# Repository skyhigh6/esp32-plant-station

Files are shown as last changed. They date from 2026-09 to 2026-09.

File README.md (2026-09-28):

# Plant Station — R17

Arduino Uno plant station prototype. Current design **R17**, controlled document issue **D02**, firmware **Uno UI v6**. Physical fit and electrical acceptance remain open.

## Start here

- [Project control and acceptance gates](PROJECT_CONTROL.md)
- [Illustrated assembly manual — PLANT-AM-001](docs/documents/AM_R17/PLANT-AM-001_R17_D02.pdf)
- [Design review — PLANT-TR-001](docs/documents/TR_R17/PLANT-TR-001_R17_D02.pdf)
- [Test and acceptance sheets — PLANT-TS-001](docs/documents/TS_R17/PLANT-TS-001_R17_D02.pdf)
- [Complete R17 download](releases/R17/Plant_Station_R17_D02.zip)
- [Document index](docs/START_HERE.html) and [operator wiring view](docs/operator_view.html) — download and open locally

## Repository structure

| Folder | Contents |
|---|---|
| `technical/cad/` | Current R17 generator, parameters, frozen STEP input and independent checker |
| `technical/print/` | 4 main parts, 11 fit trials, 8 knob choices; matching STL and STEP, source hashes, four-plate layout and four operator slicer exports |
| `firmware/` | Current Uno sketch, adjacent headers, host assertions and build instructions |
| `docs/` | Three illustrated PDFs, editable JSON/Markdown, assets, page renders and document controls |
| `references/` | Supplied USB dimension image and illustration provenance |
| `verification/` | CAD/document results, selected predecessor source basis and release checks |
| `releases/R17/` | Frozen complete package and SHA-256 manifest |
| `scripts/` | Portable document rebuild, export verification and packaging tools |

The tower replaces the broad USB cable opening with an estimated **9.8 × 4.2 mm** USB-C aperture, **Ø2.8 mm** fixing pilots at **15.2 mm** pitch, and an adjacent **Ø10 mm** DC-extension hole. Print the port coupon first. USB dimensions are authorised estimates; actual fit has not been tested.

Use the R17 tower, retained R16 lid carrying R15 geometry, retained R13 fascia/planter and **one** suitable knob. Revision suffixes identify part provenance. Do not print all alternatives.

The [four-plate Bambu Studio layout](technical/print/plate_layout/r17_plate_layout.3mf) contains the four main models. Its component geometry matches the released STL files; print settings and physical results remain unvalidated. Financial fields and an account identifier were removed from the publication copy; the original is retained locally.

The [operator slicer exports](technical/print/slicer_exports/README.md) contain four separately exported printer files. Their executable commands are preserved, with source/publication hashes and metadata changes recorded. Their inclusion records the supplied files; it does not approve their settings or physical operation.

## Traceability

`PROJECT_CONTROL.md` is the single current baseline pointer. The D02 manuals carry revision history, effective-page lists and source-backed change bars. The [print manifest](technical/print/manifest.json) identifies every selected export. The [evidence register](docs/control/evidence_register.json) identifies the documentary source basis; snapshot records are historical evidence, not current instructions.

Superseded release folders and archives have been removed from the current branch tree. Git history retains published predecessors; a verified external local backup preserves unpublished work. Repository visibility and existing history are unchanged.

## Rebuild and verify

See [document instructions](docs/README.md), [CAD instructions](technical/cad/README.md), [firmware instructions](firmware/README.md) and [verification scope](verification/README.md).

```powershell
python scripts/rebuild_documents.py
python scripts/verify_release.py
python scripts/package_release.py
```

Requires Python 3.12 and the libraries listed in `requirements-docs.txt` and `requirements-cad.txt`. The CAD runtime has a recorded shutdown exit-code anomaly; the independent export checker remains a separate gate. No physical, powered, wet or printer acceptance is implied by publication.

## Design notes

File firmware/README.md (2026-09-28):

# Arduino Uno firmware — UI v6

Current source: `arduino/PlantUno/PlantUno.ino`, with adjacent `PlantController.h` and `PlantView.h`. Target: classic ATmega328P Arduino Uno; the sketch rejects other board profiles.

## Interface

| Pin | Connection |
|---|---|
| D2 / D3 / D4 | WATER / NEXT SCREEN and held lamp test / STOP; INPUT_PULLUP switches to GND |
| D5 / D6 / D7 | Red / yellow / green lamp outputs, each with a verified current limit |
| D9 | Enabled active-HIGH relay module input; module behaviour is user reported |
| A0 / A1 | Soil signal / dose potentiometer |
| A4 / A5 | LCD SDA / SCL; LCD VCC on regulated 5 V and GND |
| D10 | Unconnected; LCD backlight controlled over I²C |

A1 is sampled once at dose start for 1,000–4,000 ms. STOP or lamp test cancels; all buttons must be released before another dose. Soil indication is advisory; no automatic watering. The screen returns to soil status after a dose; backlight turns off after 60 s idle and wakes on input activity.

See the [operator view](../docs/operator_view.html) and [current assembly manual](../docs/documents/AM_R17/PLANT-AM-001_R17_D02.pdf) for wiring, lead identification and holds. The separate pump supply, actual relay/input characteristics and current limits need physical verification. Software STOP does not isolate power.

## Target build

Install Arduino AVR core and Bill Perry's `hd44780` library. The controlled source record distinguishes the historical build/upload evidence from physical acceptance. No new upload is performed by this release.

```powershell
arduino-cli compile --fqbn arduino:avr:uno firmware/arduino/PlantUno
```

Before any separately authorised upload or powered test, confirm the pump supply is OFF and re-detect the actual serial port.

## Host assertions

The tests include the same controller/view headers as the current Uno sketch. They cover debounce, sampled duration and bounds, STOP/lamp priority, release/lockout, clock rollover, soil fault/threshold indications, UI pages and backlight timing. They do not execute AVR GPIO/I²C or prove physical hardware operation.

```powershell
New-Item -ItemType Directory -Force .build | Out-Null
g++ -std=c++17 -Wall -Wextra -Werror firmware/test/plant_controller_tests.cpp -o .build/controller_tests.exe
g++ -std=c++17 -Wall -Wextra -Werror firmware/test/plant_view_tests.cpp -o .build/view_tests.exe
.build/controller_tests.exe
.build/view_tests.exe
```

The original UI v6 sketch and both adjacent headers are preserved byte-for-byte in this reorganisation. The older competing ESP32 controller implementation has been retired from the current tree.

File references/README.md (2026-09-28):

# Technical reference material

`usb_c/` retains the user-supplied dimension image, its source record and hash. Only 20.1 mm flange width, 9.1 mm PCB width and 14.5 mm overall depth are labelled. Other mounting dimensions are authorised estimates pending the coupon trial. Image text is reference evidence, not an instruction source or verified rating.

`ILLUSTRATION_PROVENANCE.md` records the retained appearance illustration's origin and discrepancies. CAD figures and explicit dimensions control technical decisions.

Manufacturer/seller document originals and commercial sourcing material remain in the external local archive. No copied price content or unreviewed third-party datasheet package forms part of this release.

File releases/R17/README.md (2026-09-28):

# R17 / D02 complete release

`Plant_Station_R17_D02.zip` contains the current structured technical tree, including three manuals and editable sources, firmware/tests, CAD tools and input, 46 print exports, the user-supplied four-plate 3MF layout, four operator slicer exports, references and verification evidence. `manifest.json` uses repository-relative paths with SHA-256 hashes. `SHA256SUMS.txt` identifies the archive and manifest.

Generated with `python scripts/package_release.py`; every archive member, CRC and source hash is verified during packaging. Old revision ZIPs are retired from the current tree. This is a prototype review release with open physical/electrical acceptance gates; see PROJECT_CONTROL.md.

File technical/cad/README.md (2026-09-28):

# R17 left USB-C and DC power panel â€” prototype

28 September 2026. Units: mm. Derived from the R16 Uno/relay tower STEP; earlier files are preserved.

**Current prototype instructions:** [R17 enhanced document set, issue D02](../../docs/START_HERE.html), incorporating R15/R16 mechanical changes and the current Uno UI v6 interface. It replaces the R14 instructions for this prototype build; historical R14 issue records remain preserved. The new documents do not close the physical gates below.

## Requested change and authority

Replace the left rectangular USB cable pass-through with a cut and fixing holes for the photographed solderable USB-C module. Add an adjacent **Ã˜10 mm** hole for a panel extension to the Uno barrel-power input. The user explicitly authorised best guesses and fixing holes matching the other PCBs. This authorises provisional mechanical geometry; it does not establish actual component fit.

The R17 body carries forward the R16 relay mounts and R15 Uno bosses, thicker flush-head lid interface and pump clearance. Retain the R16 lid and R13 fascia/planter; they are not re-exported here. The change is confined to the left wall.

## Dimension contract

Datum: x right, y towards rear, z up. Left outside wall x=0; inside wall x=6. Connectors mount from the outside. Their cables/wiring enter the dry tower.

| Feature | Nominal dimension / position | Evidence |
| --- | --- | --- |
| Old USB opening | 28 Ã— 20, lower-left y49/z98.5 | R16 inherited geometry; closed, including chamfers |
| USB centre | y63 / z108.5 | Engineering placement; retains old opening centre |
| USB rounded rectangular cut | **9.8 Ã— 4.2**, R1.2 corners | Authorised estimate; no measured shell size |
| USB fixing centres | y55.4 and y70.6 / z108.5; **15.2** pitch | Authorised estimate; actual flange pitch unknown |
| USB printed fixing pilots | **Ã˜2.8 through** | Same nominal diameter as Uno/relay pilots; wall is 6 thick |
| Power-jack extension centre | y35 / z108.5 | Engineering placement; 28 from USB centre, towards front |
| Power-jack cut | **Ã˜10.0 through**, no added allowance | User-specified; thread and nut unmeasured |
| USB flange width / PCB width / depth | 20.1 / 9.1 / 14.5 | Supplied image dimension labels; actual component unmeasured |
| USB flange height / thickness / component fixing holes | 7.0 / 1.5 / Ã˜3.1 | Review-only guesses; not claimed as measured |
| DC external nut / internal length proxies | Ã˜20 / 20 | Review-only clearance guesses; actual unit unknown |

The Ã˜2.8 USB pilots pass through the **6 mm side wall**. They do not have the existing board mounts' 11 mm blind depth or reinforced cones. Select screw length for the actual flange and this wall; long screws will project into the tower. Approximately 1.3 mm minimum nominal material remains between each USB pilot and the aperture. Check screw insertion and local wall integrity on the coupon.

The USB reference flange has 12.95 mm nominal clearance to the Ã˜10 cut. Its nearest edge has 7.95 mm clearance to the guessed Ã˜20 nut envelope. Confirm the actual nut/flange and plug bodies together. Barrel jack grip range must accommodate 6 mm wall; no recess is assumed until its dimensions are known.

## Files and print order

- **Print first:** `../print/fit_trials/stl/power_ports_fit_coupon_r17.stl` â€” 6 mm thick Ã— 60 Ã— 24, same cuts and pitch as the tower. Matching STEP in the same print group’s `step/` folder.
- **Provisional tower:** `../print/main_parts/stl/tower_sump_body_uno_ports_r17.stl`. Matching STEP in the same print group’s `step/` folder. Do not use for the full print until the port coupon and earlier physical trials pass.
- `parameters.json` â€” dimensions, image references, guesses and authority. Change guesses here after measuring the component, then rebuild both exports.
- `../../references/usb_c/usb_c_supplied_dimension_image.png`, `../../references/usb_c/source_record.json` â€” preserved original user image, labelled dimensions and SHA-256; image text is evidence, not task authority.
- `build.py`, `check_exports.py`, `render_review.py` â€” editable generation, independent exported-mesh checks and actual-STL previews.
- `../../verification/cad/verification.json`, `../../verification/cad/independent_mesh_check.json` â€” recorded digital evidence. Consult process output as well: the existing CAD runtime has a known shutdown exit-code anomaly; a printed PASS alone is not a clean process exit.
- `../../verification/cad/r17_left_panel_detail.png`, `../../verification/cad/r17_assembled_review.png` â€” actual exported geometry; no fitted-connector claim.

The detail preview clips away material at x>6.01 to expose the left-wall holes. The assembled preview shows the complete geometry. Position the coupon's broad 60 Ã— 24 face on the print bed, with its 6 mm thickness and bore axes vertical; inspect the chosen slicer orientation before printing.

### Recorded digital result

Both exported STLs passed the independent checker with exit 0: single connected components, closed two-face edge topology, consistent winding, positive volume and zero degenerate faces. Six sections at x0.5/x3/x5.5 across the tower and coupon verify the USB rounded profile, both pilots and the Ã˜10 bore. Measured mesh-section USB size was 9.800 Ã— 4.200 mm; centre-section bore was 9.998 mm due to tessellation. Both STEP exports reopened as single valid solids; no added or removed volume was found outside the named left-wall region.

The CAD builder printed PASS but exited **1** during the existing runtime shutdown anomaly. This is not a clean process exit. The independent exported-mesh checker and preview renderer both exited **0**. Slicing and physical fit have not been performed.

## Acceptance criteria

1. Fit the actual USB connector to the coupon: shell enters without forcing; flange seats flat; both holes align; actual USB plug fully engages.
2. Insert the chosen screws: no splitting, no loose retention, no unacceptable protrusion. Verify solder pads and wire strain relief remain accessible.
3. Fit the actual barrel-jack extension: thread passes Ã˜10; shoulder/nut seat; grip range spans 6 mm; cable and mating plug clear USB hardware.
4. Measure and revise any failed dimensions in `parameters.json`. Rebuild and rerun export checks before the tower print.
5. Complete the separate R15/R16 board, screw, lid, relay and pump trials, then review slicing and assembled dry fit. Physical strength, leaks and electrical commissioning remain open.

The two openings provide mechanical access for alternative USB and barrel-input supply connections. No supply voltage, polarity, simultaneous-source behaviour or USB-C negotiation circuit is approved by these CAD files. The image's 6-pin/5 A text is supplier information, not a verified electrical rating.

## Rebuild

```powershell
python technical/cad/build.py
python technical/cad/check_exports.py --print-root .build/cad --report-dir .build/cad
python technical/cad/check_exports.py
python technical/cad/render_review.py
```

R17 is the current prototype baseline. Earlier instructions are superseded for this build; physical acceptance remains open. CAD rebuilds go to .build/cad until reviewed and deliberately promoted to technical/print.

The first checker command tests regenerated outputs; the second tests released outputs under technical/print. During relocation verification both regenerated STL hashes matched the released originals and the independent checker exited 0. The CAD process terminated after export with Windows status 0xC0000005 / exit -1073741819; see verification/cad/regeneration_process.json. The abnormal process termination remains open. Original digital results above retain their original evidence date and exit status.

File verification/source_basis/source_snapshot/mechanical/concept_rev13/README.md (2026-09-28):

# R13 annotated mechanical revision

14 September 2026. Supersedes R12; prior files preserved. Units: mm; x right, y rear, z up.

## Changes

1. Removed the separate hose clip, tower shelf and clip pilot.
2. Supported hose riser now uses R7 vertical outside rounds and R3 top rounds. Separate 10 mm tube and 8 mm pump-wire passages retained.
3. Both lower fascia screw supports now have full feet and added concave R2 floor roots. Rounded-away lower support profiles removed.
4. Removed obsolete battery screw bores and dry-floor fixing pads/pilots. Integrated 72 x 22 mm holder saddle and 6 x 2.5 mm tie tunnel retained.
5. Independent sensor entry lowered to y65/z64, diameter 8: lower edge level with the z60 sump rim. Matching local planter skirt relief clears the sensor lead outside the soil cavity. Pump-wire crossover remains y92/z81.

The organic treatment changes the riser's external shape; actual hose bend radius and retention require a physical trial. The low sensor opening is not a sealed gland or an approved maximum fill level.

## Parts and assembly

Four main parts: tower_sump_body, fascia_charcoal, top_cover_sage and planter_sage. Body 207 x 100 x 158; assembled roof height 161. Nineteen STL/STEP exports include eight knob options, six fit coupons and a USB marking blank. Print only the selected knob.

Replace R12 body and planter. Fascia, roof and existing accessory geometries are retained. Remove the old hose clip. Do not use old battery/clip screws.

See the separate customer-format kit manual and design review under output/pdf. Electronics remain a prototype: exact carrier pin mapping, power path, component identity, third-control role, LCD operation and commissioning are open. No powered operation is authorised by a CAD check.

## Validation

verification.json: four valid main solids, six zero-volume pair intersections, positive/negative feature probes and 61 sampled planter lift checks in 2 mm increments through 120 mm.
independent_mesh_check.json: 19 closed, consistently wound, positive-volume one-component meshes, two faces per edge, no degenerate faces; mount, route and accessory sections checked.
step_check.json: 19 re-imported valid single solids; four-solid assembly; STL bounds within 0.03 mm and volume within 0.2 percent.

Build completed with PASS and no assertion traceback, followed by the existing CadQuery shutdown exit 1. Re-import checker likewise passed then exited 1. Independent mesh and section rendering completed with exit 0. No slicing, full mesh self-intersection, continuous swept-lift, physical fit, strength, leak or electrical tests performed.

## Radius review

Reviewed the source treatments for cavity floor/vertical edges, shell rim, upper supports, PCB root fillets and tip chamfers, USB chamfers, sump/planter/lip vertical corners and service riser. Concave cavity and standoff roots add material to the assembled body; outer corner rounds remove material intentionally. The lower foot treatment was the identified root error and is replaced on both sides. Geometry validity and preview review are not strength verification.

## Rebuild and inspect

Run build.py, check_exports.py, check_step.py and render_cable_section.py using a Python environment containing CadQuery 2.8, trimesh, NumPy, VTK, matplotlib and networkx. Run scripts/build_guide_r13.py with ReportLab after the illustration is present. The builder imports the workspace-local .tools/cad-runtime when present.

Viewer: python -m http.server 8770 --bind 127.0.0.1 --directory mechanical/concept_rev13
Open http://127.0.0.1:8770/viewer/

Source dimensional references remain mechanical/concept_rev8/references and docs/PROJECT_CONTROL.md. This revision changes no firmware. AI_IMAGE_PROVENANCE.md records the generated illustration and its limitations.

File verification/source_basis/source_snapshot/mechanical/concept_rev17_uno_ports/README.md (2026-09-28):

# R17 left USB-C and DC power panel — prototype

28 September 2026. Units: mm. Derived from the R16 Uno/relay tower STEP; earlier files are preserved.

**Current prototype instructions:** [R17 enhanced document set, issue D02](../../output/pdf/Plant_Controlled_Set_R17/START_HERE.html), incorporating R15/R16 mechanical changes and the current Uno UI v6 interface. It replaces the R14 instructions for this prototype build; historical R14 issue records remain preserved. The new documents do not close the physical gates below.

## Requested change and authority

Replace the left rectangular USB cable pass-through with a cut and fixing holes for the photographed solderable USB-C module. Add an adjacent **Ø10 mm** hole for a panel extension to the Uno barrel-power input. The user explicitly authorised best guesses and fixing holes matching the other PCBs. This authorises provisional mechanical geometry; it does not establish actual component fit.

The R17 body carries forward the R16 relay mounts and R15 Uno bosses, thicker flush-head lid interface and pump clearance. Retain the R16 lid and R13 fascia/planter; they are not re-exported here. The change is confined to the left wall.

## Dimension contract

Datum: x right, y towards rear, z up. Left outside wall x=0; inside wall x=6. Connectors mount from the outside. Their cables/wiring enter the dry tower.

| Feature | Nominal dimension / position | Evidence |
| --- | --- | --- |
| Old USB opening | 28 × 20, lower-left y49/z98.5 | R16 inherited geometry; closed, including chamfers |
| USB centre | y63 / z108.5 | Engineering placement; retains old opening centre |
| USB rounded rectangular cut | **9.8 × 4.2**, R1.2 corners | Authorised estimate; no measured shell size |
| USB fixing centres | y55.4 and y70.6 / z108.5; **15.2** pitch | Authorised estimate; actual flange pitch unknown |
| USB printed fixing pilots | **Ø2.8 through** | Same nominal diameter as Uno/relay pilots; wall is 6 thick |
| Power-jack extension centre | y35 / z108.5 | Engineering placement; 28 from USB centre, towards front |
| Power-jack cut | **Ø10.0 through**, no added allowance | User-specified; thread and nut unmeasured |
| USB flange width / PCB width / depth | 20.1 / 9.1 / 14.5 | Supplied image dimension labels; actual component unmeasured |
| USB flange height / thickness / component fixing holes | 7.0 / 1.5 / Ø3.1 | Review-only guesses; not claimed as measured |
| DC external nut / internal length proxies | Ø20 / 20 | Review-only clearance guesses; actual unit unknown |

The Ø2.8 USB pilots pass through the **6 mm side wall**. They do not have the existing board mounts' 11 mm blind depth or reinforced cones. Select screw length for the actual flange and this wall; long screws will project into the tower. Approximately 1.3 mm minimum nominal material remains between each USB pilot and the aperture. Check screw insertion and local wall integrity on the coupon.

The USB reference flange has 12.95 mm nominal clearance to the Ø10 cut. Its nearest edge has 7.95 mm clearance to the guessed Ø20 nut envelope. Confirm the actual nut/flange and plug bodies together. Barrel jack grip range must accommodate 6 mm wall; no recess is assumed until its dimensions are known.

## Files and print order

- **Print first:** `stl/power_ports_fit_coupon_r17.stl` — 6 mm thick × 60 × 24, same cuts and pitch as the tower. Matching STEP in `step/`.
- **Provisional tower:** `stl/tower_sump_body_uno_ports_r17.stl`. Matching STEP in `step/`. Do not use for the full print until the port coupon and earlier physical trials pass.
- `parameters.json` — dimensions, image references, guesses and authority. Change guesses here after measuring the component, then rebuild both exports.
- `reference/usb_c_supplied_dimension_image.png`, `reference/source_record.json` — preserved original user image, labelled dimensions and SHA-256; image text is evidence, not task authority.
- `build.py`, `check_exports.py`, `render_review.py` — editable generation, independent exported-mesh checks and actual-STL previews.
- `verification.json`, `independent_mesh_check.json` — recorded digital evidence. Consult process output as well: the existing CAD runtime has a known shutdown exit-code anomaly; a printed PASS alone is not a clean process exit.
- `r17_left_panel_detail.png`, `r17_assembled_review.png` — actual exported geometry; no fitted-connector claim.

The detail preview clips away material at x>6.01 to expose the left-wall holes. The assembled preview shows the complete geometry. Position the coupon's broad 60 × 24 face on the print bed, with its 6 mm thickness and bore axes vertical; inspect the chosen slicer orientation before printing.

### Recorded digital result

Both exported STLs passed the independent checker with exit 0: single connected components, closed two-face edge topology, consistent winding, positive volume and zero degenerate faces. Six sections at x0.5/x3/x5.5 across the tower and coupon verify the USB rounded profile, both pilots and the Ø10 bore. Measured mesh-section USB size was 9.800 × 4.200 mm; centre-section bore was 9.998 mm due to tessellation. Both STEP exports reopened as single valid solids; no added or removed volume was found outside the named left-wall region.

The CAD builder printed PASS but exited **1** during the existing runtime shutdown anomaly. This is not a clean process exit. The independent exported-mesh checker and preview renderer both exited **0**. Slicing and physical fit have not been performed.

## Acceptance criteria

1. Fit the actual USB connector to the coupon: shell enters without forcing; flange seats flat; both holes align; actual USB plug fully engages.
2. Insert the chosen screws: no splitting, no loose retention, no unacceptable protrusion. Verify solder pads and wire strain relief remain accessible.
3. Fit the actual barrel-jack extension: thread passes Ø10; shoulder/nut seat; grip range spans 6 mm; cable and mating plug clear USB hardware.
4. Measure and revise any failed dimensions in `parameters.json`. Rebuild and rerun export checks before the tower print.
5. Complete the separate R15/R16 board, screw, lid, relay and pump trials, then review slicing and assembled dry fit. Physical strength, leaks and electrical commissioning remain open.

The two openings provide mechanical access for alternative USB and barrel-input supply connections. No supply voltage, polarity, simultaneous-source behaviour or USB-C negotiation circuit is approved by these CAD files. The image's 6-pin/5 A text is supplier information, not a verified electrical rating.

## Rebuild

```powershell
python mechanical/concept_rev17_uno_ports/build.py
python mechanical/concept_rev17_uno_ports/check_exports.py
python mechanical/concept_rev17_uno_ports/render_review.py
```

Scope is this local R17 prototype. This does not supersede the issued R14 baseline or close any physical acceptance gate.

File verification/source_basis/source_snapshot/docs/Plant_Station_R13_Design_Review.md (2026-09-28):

# R13 | Design change and verification

14 September 2026 / Supersedes R12 mechanical geometry / Units: mm



Five browser annotations implemented. Four main enclosure parts; selected knob and fit coupons are separate. The illustration is generated appearance guidance; the exported CAD remains dimensional authority.

Body: 207 x 100 x 158 mm. Overall roof height: 161 mm. Changes are local to the combined body and planter; fascia, roof and knob interfaces are retained.

# Annotation disposition and radius audit

1. <b>Clip:</b> removed the separate hose clip, its shelf and shelf pilot. The tower has no retained clip attachment point.

2. <b>Hose route appearance:</b> enlarged vertical outside rounds from R1 to R7 and added R3 top rounds to the supported riser. Separate 10 mm tube and 8 mm pump-wire bores remain. Physical tubing bend radius is still unknown.

3. <b>Screw block:</b> replaced the rounded lower support profile with full feet and added concave R2 floor roots on both sides. Material probes verify the feet are filled. Audited cavity floor/vertical, shell rim, upper webs, board roots/tips, USB chamfers, sump/planter/lip and riser edge treatments; no further inverted root treatment identified in the source review.

4. <b>Battery:</b> removed both old holder bores and underlying unused pad/pilot features. The integrated saddle and tie tunnel remain.

5. <b>Sensor lead:</b> entry centre lowered from z128 to z64; its 8 mm hole starts at the z60 sump rim. A local skirt relief avoids a cable clash. This interpretation targets the separate sensor entry, not the pump-wire crossover, which remains at z81.



Nominal datum: x right, y rear, z up; fascia faces forward. All new radii and route clearances are design choices, not measured component values.

# Geometry evidence and remaining acceptance



Export checks: 19 STL meshes, 19 single-solid STEP parts, four-solid assembly; six main-part pair intersections; 61 sampled planter lift positions from 0 to 120 mm. See accompanying JSON records for measured results and hashes.

Checks include closed meshes, consistent winding, two faces per edge, no degenerate faces, positive volumes, STEP validity, matching bounds/volumes, feature sections and positive/negative solid probes. Sampled lift checks do not constitute a continuous swept-volume proof.

Physical fit, slicing, support removal, loads, water tightness, cable bend/retention and powered operation remain unverified. Full mesh self-intersection checking has not been performed. The local CadQuery runtime may exit 1 during shutdown even after assertions pass; distinguish that from any assertion traceback.

The low sensor entry is not a seal or approved fill level. Validate capillary, splash and drain-back behaviour before wet operation. Existing electrical uncertainties and provisional third-control role remain unchanged.

Deliverables: editable build.py, STL/STEP exports, assembly STEP, actual CAD images and sections, AI illustration/prompt, viewer, this review and the separate customer-format kit instructions. R12 is preserved.

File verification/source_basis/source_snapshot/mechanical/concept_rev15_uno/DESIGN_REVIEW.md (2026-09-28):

# R15 Uno mechanical change review

27 September 2026. Units: mm. R14 is the printed baseline. R15 is a prototype geometry issue with physical fit trials pending.

## 1. Current state

| Feature | R14 geometry | Physical finding |
|---|---|---|
| Uno mounts | Four 6.0 outside-diameter bosses with 2.8 blind pilots, 11 deep from the board seat | Operator reports splitting during screw insertion. New Photo 2 shows deformed/split printed bosses; loose filament is excluded from the defect assessment. Screw dimensions and print material remain unmeasured. |
| Roof | 3.0 thick; four 3.4 through-holes, without head recesses | Operator requests a thicker roof and flush screw heads. New Photo 1 shows a screw against a ruler, but does not establish that the same screw is used for the lid or a precise head diameter. |
| Pump/tube route | Provisional 10.0 tube bore at x123/y92; wet-side service relief x106.5–130, y83–94, z18–52 | The earlier installed-pump photo and new Photo 3 show the outlet and connected tube. New Photo 4 identifies the lower riser ledge as the requested clearance area. |

The R14 tower/sump is one printed body. The R13 fascia and planter are retained unless an interface check identifies another change.

## 2. Constraints and unknowns

- Preserve the asymmetric Uno mounting centres, board seating plane and fascia interface.
- Keep the tube and pump on the wet side of the partition; retain a continuous dry-side wall and serviceable pump-lead route.
- Maintain lid screw engagement and tool access after changing lid thickness and head pockets.
- Record actual screw type, major diameter, head diameter and height, length, material, print orientation and the location of the split. A 2.8 pilot does not establish a qualified thread-forming fit.
- The ruler photos support approximate hardware scale, but are not calliper measurements of the screw head, tube or installed clearance. Verify those dimensions during fit trials.
- The R14 vertical passages and nominal 10.0 tube bore are retained; Photo 4 points to the ledge below them.

## 3. Options and recommendation

| Feature | Option | Trade-off |
|---|---|---|
| Uno bosses | Increase wall thickness along the screw engagement length; add a gradual root taper and full-depth trial coupon | Retains the simple four-screw assembly. Pilot and boss sizes must be selected against the actual screw and printed material. A taper alone does not cure splitting at the free end. |
| Uno bosses | Heat-set inserts or captive nuts | Better repeated service, but needs insert/nut dimensions, installation access and a larger local envelope. |
| Roof | Increase thickness and add four head pockets sized to the selected fastener | Gives flush heads; pocket depth must leave a continuous load-bearing floor and enough material at the outer edge. |
| Pump route | Rotate or shift the pump with the tube attached | May avoid a geometry change but can obstruct planter insertion or create a tight tube bend. |
| Pump route | Extend the existing wet-side relief down to the sump floor | Directly removes the ledge identified in Photo 4, while retaining the rear wall and dry-side web. The real tube still needs a fit trial. |

Selected R15 prototype: four 8.5 mm tip / 10.0 mm root tapered bosses, retaining 2.8 mm x 11 mm pilots; 5.5 mm roof with 6.6 mm x 2.5 mm head pockets; lower the wet-side relief from z18 to z4 and extend its right edge from x130 to x132. The sump floor remains 4 mm and the relief stops at y94, leaving a nominal 6 mm rear band and at least 12.5 mm of dry-side web. Existing tube/wire bores reduce the local rear-wall thickness. The altered roof projects 1.5 mm beyond the tower sides to retain material around the pockets. See README.md for files and trial order.

## 4. Acceptance criteria

1. A full-length boss coupon printed in the intended material and boss orientation takes the selected screw without splitting, excessive board load, bottoming or loss of retention. Trial both 2.8 and 3.0 mm pilots; the exported body uses 2.8 mm until the trial supports a change.
2. All four Uno mounting holes register and seat without forcing the board. Inspect solder joints and nearby components against the enlarged bosses and screw heads.
3. Lid screws fit with heads flush or below the outer face, without breaking through the remaining floor or side edge. Lid seats against the unchanged body interface.
4. Pump and connected tube can be installed and removed without force or kinking, first against the local route trial and then in the complete body. The tube remains in the wet route; the dry-side partition remains continuous. Inspect and test the printed body for leakage before wet operation.
5. R15 STEP and STL exports are single valid solids with closed, consistently wound, positive-volume meshes. Critical sections, assembled clearances and the changed-volume regions pass digital checks against R14; printed fit and leak tests remain open.

## 5. Remaining physical evidence

- Screw type and calliper dimensions; printer material, orientation and layer settings; repeatable screw trial result in the matching R15 coupon.
- Confirmation whether the pictured screw is used for the roof, and actual lid head diameter/height and engagement.
- Pump/tube fit result in the local route trial and full body, followed by a controlled wet-side leak check.

Digital geometry is complete for a prototype print trial. Physical acceptance and the correct pilot/head fit remain open.

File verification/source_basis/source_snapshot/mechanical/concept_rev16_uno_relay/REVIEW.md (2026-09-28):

# R16 Uno relay mount — design review

27 September 2026. Units: mm. Baseline: R15 Uno prototype body. R15 files and checks remain the issued comparison set.

## Requested change

Add mounts for the actual pump relay module below the Arduino Uno, inside the dry tower. An R16 prototype body, retained R15 lid and four-boss trial coupon have been exported. Physical fit is still open.

## Supplied part reference

- User-supplied listing: https://www.amazon.co.uk/dp/B0CSJQZ89V (ASIN B0CSJQZ89V).
- The supplied photographs show the delivered red PCB with a Songle SRD-05VDC-SL-C relay, four mounting holes and a screw terminal block at each end. Both photographs show the component side; the underside is still unseen.
- A [seller listing for the apparent module](https://ibspot.com/us/products/gtiwung-pack-of-10-one-channel-relay-module-5-v-1-channel-relay-board-with-optocoupler-isolation-high-level-trigger-relay-module-low-l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) gives 50 × 26 × 18.5 overall, Ø3.1 holes and 44.5 × 20.5 hole-centre pitch. The 50 × 26 PCB size is consistent with the ruler photographs. Hole pitch, PCB thickness and height remain nominal until checked on the physical board.
- The user intends to use the same screws as for the Uno. The screw shown earlier by a ruler does not establish a reliable major diameter or head size; the 2.8 mm pilot remains a coupon trial.

## Options considered

| Layout | Benefit | Limit |
| --- | --- | --- |
| Vertical board below Uno | Short horizontal reach to side walls | The nominal 50 mm board would consume almost all of the 51 mm gap between battery saddle and Uno; no useful end clearance. |
| Horizontal board on rear dry wall | 26 mm high, front screw access, 12 mm nominal gap above battery and 13 mm below Uno | Wire bends at the two end terminals require a physical trial. **Selected for R16.** |
| Side-wall mount | Frees rear wall | Obstructs service access and risks the existing left-side connector aperture. |

## R16 nominal placement

- PCB x21–71, z33–59, underside seating at y76; populated face toward the removable fascia.
- Hole centres `(23.75,35.75)`, `(23.75,56.25)`, `(68.25,35.75)`, `(68.25,56.25)` in x/z.
- Contacts face right, toward the sump and pump cable route; DC+/DC-/IN1 face left. This is a routing choice for trial, not an electrical wiring approval.
- Four tapered rear-wall bosses: Ø8.5 at the seating tip, Ø10 at the root, 19 mm projection, Ø2.8 × 11 mm blind pilot. The same screw is intended as the R15 Uno bosses.
- Nominal side spaces to the inner shell walls: 15 mm at the logic terminal end, 19 mm at the contact terminal end. The stated component height gives a nominal frontmost y55.9; the fascia's *assumed* button rear limit is y39, leaving 16.9 mm in that direction. Actual terminal/wire bend and button hardware need assembly trial.
- No new penetration is made through the wet/dry wall.

## Current CAD space

- Uno board envelope: x13.71–82.29, z72.00–125.34; underside seating plane y76. Its lower edge is z72.
- Integrated battery saddle occupies approximately x12–84, y30–60 and rises to z21. The gap between its top and the nominal Uno lower edge is 51 mm before clearances.
- Rear dry-wall inner face is near y94. Both the Uno and R16 relay bosses project to y76; the relay seat and same-screw choice remain subject to physical fit.
- Fascia controls occupy the front of the tower. Their rearward envelopes and wire bends are not established by this space calculation.
- The R15 pump riser relief is in the wet-side sump. Relay mounts must remain in the dry tower and preserve the wet/dry partition.

## Evidence still needed from the relay

1. Underside photograph beside a ruler, with solder tails visible around all four holes.
2. Measured mounting-hole diameter and pitch, PCB thickness, rear solder projection and assembled component height.
3. Confirm the existing Uno screws pass through all four relay holes and their heads clear the adjacent terminal blocks/PCB parts.
4. Check actual print material/orientation and whether the Ø2.8 pilot accepts the screws without splitting.
5. Trial the contact and logic wire entries, bend radii, screwdriver access and relay removal with the Uno, controls and fascia present.

## Design and acceptance intent

- Preserve the R15 Uno bosses, roof and pump-clearance changes while modifying only the dry-tower mount region needed for the relay.
- Use the measured asymmetric mounting pattern if present. Avoid forcing the PCB, contacting solder joints or obscuring terminals.
- Leave accessible service loops, a reachable disconnect, and separation between relay contact/pump wiring and sensor/LCD wiring.
- Check board insertion/removal with the Uno, fascia and battery saddle in place. Check wall continuity and digital intersections before a physical fit coupon and full-body print.
- The relay module's electrical rating, reset state and pump-power path are governed by the current Uno relay wiring review; CAD fit does not close those checks.

## Digital verification and release status

- R16 `build.py` reports PASS after CAD solid validation, STEP readback, mesh export and named interference checks, but this CAD runtime returns exit code 1 during shutdown. That is **not** a clean build result.
- The independent `check_exports.py` exits 0: all three R16 STLs are closed, consistently wound single components with positive volume, two-face edges and no degenerate facets. Sections confirm all four relay pilots and tapered boss diameters on the body and fit coupon. The R16 lid has the same bounds and volume as the retained R15 lid.
- Digital PCB/nominal component envelopes do not intersect the R16 body; all body changes lie in the named dry-side relay-mount region. These checks do not prove physical insertion, screw retention, wire fit or electrical suitability.
- Recommended next print: the four-boss relay mount trial coupon. Mount the actual board with the actual screws, then approve or revise the full-body R16 STL. The R15 Uno screw, lid head and pump trials remain separate open gates.

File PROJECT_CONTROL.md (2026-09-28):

# Plant Station — current project control

**Baseline:** R17 prototype / document issue D02 / Uno UI v6. **Date:** 28 September 2026. **Status:** issued for prototype review; physical and electrical acceptance open.

## Configuration authority

| Item | Current authority |
|---|---|
| Assembly, wiring, holds | [PLANT-AM-001 R17 D02](docs/documents/AM_R17/PLANT-AM-001_R17_D02.pdf) |
| Change justification and unknowns | [PLANT-TR-001 R17 D02](docs/documents/TR_R17/PLANT-TR-001_R17_D02.pdf) |
| Acceptance records | [PLANT-TS-001 R17 D02](docs/documents/TS_R17/PLANT-TS-001_R17_D02.pdf); A17-01–A17-13 open |
| Firmware | `firmware/arduino/PlantUno/`; UI v6 source preserved unchanged |
| Geometry parameters | `technical/cad/parameters.json`; mm; x right, y rear, z up |
| Manufacture exports | `technical/print/manifest.json`; four main parts plus one chosen knob |
| User plate layout | `technical/print/plate_layout/r17_plate_layout.3mf`; source/published hashes and geometry comparison in `verification/plate_layout.json`; settings unvalidated |
| Operator slicer exports | `technical/print/slicer_exports/`; four supplied printer files; original/publication hashes, comment-only toolpath change and MD5 checks in `verification/slicer_exports.json`; no machine execution performed |
| Documentary lineage | `docs/control/`; selected source basis under `verification/source_basis/` |
| Release integrity | `releases/R17/manifest.json` and `SHA256SUMS.txt` |

## Incorporated changes

- **R15:** reinforced Uno bosses, 5.5 mm lid with recessed heads, pump-route relief.
- **R16:** four relay PCB mounting bosses below the Uno.
- **R17:** left mounted USB-C aperture/pilots and adjacent Ø10 mm barrel-input extension hole. Unmeasured USB details use estimates explicitly authorised by the user.
- **UI v6:** three button/lamp interface; D9 active-HIGH relay; A1 samples a 1,000–4,000 ms dose; post-dose soil display; 60 s LCD backlight timeout.
- **D02:** current assembly manual, design review and test sheets issued directly at R17. No intermediate R15/R16 manuals are asserted. AM predecessor R14 D01; TR predecessor R13 D01; TS newly assigned.

Repository reorganisation changes file locations and publication tooling. It does not change current firmware, R17 geometry or issued PDF content. Selected inherited STL/STEP files retain their originating revision suffixes and hashes.

## Evidence and limitations

Digital evidence records valid STEP solids, closed/wound STL meshes and named port sections. The original CAD builder printed PASS and exited 1 during a runtime shutdown anomaly; this is not a clean build. The independent exported-mesh checker exited 0. PDF layout, controls and clean rendered-page rebuilds are recorded separately.

Regeneration at the new paths reproduced both released R17 STL hashes and passed the independent section checker (exit 0). The CAD process again terminated abnormally after export, this time with Windows status `0xC0000005` / exit `-1073741819`. This remains an open runtime anomaly; regeneration is not recorded as a clean process success. Canonical released exports remain unchanged.

The 27 September interface source records an uploaded UI v6 and serial LCD status 0 with idle/activity backlight response. That historical serial/software evidence does not establish physical display reliability, relay timing, delivered volume or lamp performance. The user's report of operation remains reported evidence. This publication performs no upload or hardware operation.

## Open acceptance gates

1. Fit actual USB module, screws and mating plug to the port coupon; verify estimated pitch and aperture, flange seating, local wall strength and solder access.
2. Fit the actual DC extension, nut and plug; verify Ø10 bore, 6 mm panel grip, cable depth and connector clearance.
3. Complete Uno/relay screw and underside-clearance trials, recessed lid trial and pump-route trial; select the physical knob fit.
4. Inspect slicer layers, printing orientation, dry assembly, strength and leakage.
5. Identify USB-C power/data/CC wiring, source voltage/current, barrel polarity and supply interaction before connecting power. Supplier “6 pin / 5 A” image text is not a verified rating.
6. Verify button leads/current limits, relay reset behaviour, pump ratings, LCD reliability, dose timing and delivered volume. STOP is software cancellation, not electrical isolation.

Detailed test criteria and blank actual-result fields are in PLANT-TS-001. Owners: **Unassigned**. Target dates: **Not set**. No acceptance gate is closed by this release.

## Recovery and change control

Pre-cleanup published baseline: `18ab0d889db349c712b43624d315e4f15ed3ebe2`. Earlier published work remains in Git history; unpublished files and a verified Git bundle are retained in an external local backup. The current tree contains only the R17 deliverables and required lineage records. No force push or history rewrite is part of this change.

Revise measured dimensions in the editable source, generate trial outputs to `.build/`, rerun independent checks, review affected document pages and deliberately promote accepted digital outputs. Update the controlled manifests and issue records before making another release. Physical results require actual observations recorded against this configuration.

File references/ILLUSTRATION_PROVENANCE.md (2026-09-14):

# R13 appearance illustration

Generated with the built-in image-generation tool on 14 September 2026 using `assembly.png` as reference. Output: `product_ai.png`.

This is an appearance illustration, not dimensional authority. Fitted electronics, plant, tubing and LED colours are illustrative. The image depicts a sound grille where CAD has one 4 mm opening. No electrical operation or physical assembly is proven by this image.

## Prompt

Use case: product-mockup. Create a realistic finished-kit studio product illustration using the reference R13 CAD as the strict shape and proportions authority. Preserve left tall sage-green electronics tower, charcoal rectangular front fascia, right smaller sage-green planter on integral sage-green sump, rounded corners, flat screw-fixed roof, exact front openings arrangement. Populate LCD opening with a dark unlabelled LCD, three small LEDs and three metal pushbuttons below them, one lower ribbed knob and tiny sound outlet. Add a modest green herb in soil in the right planter and a thin discreet curved water tube emerging from the rear service riser into the soil. No hose clip or attachment shelf on tower. Do not add controls, bases, logos or text. Same three-quarter front-left viewpoint, warm off-white studio background, subtle matte 3D printed texture, soft clear lighting, complete product centred with generous whitespace. Appearance illustration only; do not invent additional seams or features.

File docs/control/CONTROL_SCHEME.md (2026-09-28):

# R17 / D02 control scheme

Issued 28 September 2026 for prototype review. Current instruction set; physical and electrical acceptance remain open.

## Identity and baseline

PLANT-AM-001 (assembly manual), PLANT-TR-001 (design review), PLANT-TS-001 (test/acceptance sheets). Design R17 is distinct from document issue D02 and Uno firmware UI v6. D02 incorporates new current technical content using the prior D01 enhanced format; it is not cosmetic restyling alone.

AM predecessor: R14 D01. TR predecessor: R13 D01. TS is newly assigned; no earlier TS issue is asserted. R15/R16 are source-backed mechanical changes incorporated here without intermediate manual issues. Prior originals are retained in Git history and the external local backup; selected D01 control records are retained in verification/source_basis.

## Format and change bars

A4 portrait; 40 mm binding/history zone; Helvetica; grey table rules; revision/control pages; every-page effective issue; section/page navigation; numbered header/footer. Bars apply only to source-backed surviving paragraphs/rows. Mixed illustrations remain unbarred and carry configuration captions. Every bar resolves to change_matrix.json. R17 electrical labels mark incorporation into the manual, not the date of software introduction.

## Status

All physical action owners: Unassigned; target dates: Not set. Actions A17-01 through A17-13 remain open. Serial/software/digital evidence is labelled; test actuals are blank/Not tested. CAD shutdown exit 1 is retained as an anomaly. No printer, hardware, upload or external publication is performed by the documentation issue.

## Deliverables and rebuild

Each document folder contains PDF, editable JSON, Markdown companion, image assets, placement manifest, renders and content/visual audit. Build the PDFs with tooling/build_document.py using Python with reportlab, pymupdf and pillow. Assets and JSON are self-contained. The current JSON and assets are the editable document sources. Superseded checkout-dependent authoring scripts remain in the external backup. Selected STL/STEP files are preserved byte-for-byte in technical/print; do not print every option.

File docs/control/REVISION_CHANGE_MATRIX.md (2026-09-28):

# R17 revision change matrix

The prior D01 matrix is preserved in verification/source_basis/previous_control. This matrix selects surviving historical changes and adds the new R15-R17 changes. Source comparison is not physical acceptance.

| ID | Label | Change | Frozen source basis |
|---|---|---|---|
| T06-1 | R6 | 60 mm sump and provisional pump envelope | mechanical/concept_rev6/README.md |
| T07-2 | R7 | 75 x 31 LCD centres and 71.4 x 24.6 aperture | mechanical/concept_rev7/README.md |
| T08-3 | R8 | Piezo/LED seats and adhesive precautions | mechanical/concept_rev8/README.md |
| T08-4 | R8 | Knob variants and axial clearance | mechanical/concept_rev8/README.md |
| T10-1 | R10 | Integrated tower/sump body | mechanical/concept_rev10/README.md |
| T11-1 | R11 | Integrated holder saddle and tie slot | mechanical/concept_rev11/README.md |
| T12-1 | R12 | Separate tube/wire routes | mechanical/concept_rev12/README.md |
| T13-1 | R13 | No separate hose clip or tray | mechanical/concept_rev13/README.md |
| T13-4 | R13 | Sensor entry z64 and lower edge z60 | mechanical/concept_rev13/README.md |
| T14-1 | R14 | Asymmetric Uno board mounting centres | mechanical/concept_rev14_uno/README.md |
| T15-1 | R15 | Reinforced Uno bosses after reported splitting | mechanical/concept_rev15_uno/DESIGN_REVIEW.md |
| T15-2 | R15 | 5.5 mm lid with flush-head pockets | mechanical/concept_rev15_uno/DESIGN_REVIEW.md |
| T15-3 | R15 | Pump relief lowered to z4 and extended to x132 | mechanical/concept_rev15_uno/DESIGN_REVIEW.md |
| T16-1 | R16 | Four relay mounts below Uno | mechanical/concept_rev16_uno_relay/REVIEW.md |
| T17-1 | R17 | Mounted USB-C cut replaces old pass-through; DC diameter 10 | mechanical/concept_rev17_uno_ports/README.md |
| T17-2 | R17 | Current UI v6 three-button and lamp/relay interface incorporated into manual | docs/UNO_BUTTON_RELAY_REVISION_2026-09-27.md |
| T17-3 | R17 | Current dose, soil status, display return and backlight behaviour incorporated | firmware/arduino/PlantUno/PlantUno.ino |
| T17-4 | R17 | Current digital evidence and cumulative physical acceptance plan | mechanical/concept_rev17_uno_ports/verification.json |
| T17-5 | R17 | USB/barrel extensions remain an electrical interface hold | mechanical/concept_rev17_uno_ports/README.md |

## Supersession and gaps

R14 diameter-6 Uno supports, 3 mm unrecessed roof, broad USB cable opening and motor-disabled/spare-button instructions are superseded for the current build. R15/R16 manual PDFs are deliberately not created. R1-R4 and prior unlocated PDFs remain unknown, as documented in the previous inventory. R17 figure captions identify retained R13/R16 source views; no changed detail is falsely claimed as a measured fit.

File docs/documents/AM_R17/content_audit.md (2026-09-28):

# PLANT-AM-001 content audit

New integrated R17 content, reconciled against preserved R14/R13 predecessor JSON, R15/R16 mechanical records, R17 exports/parameters and current UI v6 source/interface record. Historical disabled-output, spare-button, roof and broad USB-window instructions are superseded in this current issue. Updated wiring figures are newly drawn from the recorded interface. Historical route/fascia/relay figures are explicitly captioned; no mixed-detail illustration receives blanket revision bars. All physical results remain Not tested/Open.

The shared matrix resolves every printed revision label. R17 electrical labels mean newly incorporated manual content; firmware remains UI v6, dated 27 September. Scope and document history do not invent intervening PDFs.

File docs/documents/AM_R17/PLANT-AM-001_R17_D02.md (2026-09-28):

# Plant Station R17 - Assembly Manual

**PLANT-AM-001 / R17 / D02 / 28 September 2026**

Issued for prototype review; physical acceptance open

Current mechanical configuration: R17 integrated body, R16 lid (R15 geometry), R13 fascia and planter. Electrical reference: frozen Uno UI v6 source and 27 September interface record. Fit, powered wet operation and unattended operation remain unaccepted.

## Revision control

- R5-R13 / source history: Earlier assembly and mechanical changes remain traceable through the preserved D01 matrix. Missing document editions are not invented.
- R14 / preceding manual: AM R14 D01: Uno mounting and motor-disabled bench v2. TR's latest located same-family PDF is R13 D01; no TR R14 PDF is assumed.
- R15 / 27 Sep 2026: Reinforced Uno bosses, thicker recessed-head lid and additional pump relief; source changes incorporated at R17, physical trials open.
- R16 / 27 Sep 2026: Four relay bosses below Uno; source change incorporated at R17; actual underside and hole pitch unmeasured.
- UI v6 / 27 Sep 2026: Three buttons and integrated lamps, enabled active-HIGH relay, 1-4 s request, soil display and 60 s backlight timeout. Firmware revision is independent of mechanical R17.
- R17 / 28 Sep 2026: Mounted USB-C cut and pilots, adjacent diameter 10 DC extension hole; estimated dimensions authorised; coupon fit required.
- D02 / 28 Sep 2026: Integrated current R17 document issue. Uses the established enhanced template, controls and cumulative revision bars. No R15/R16 manual issues created.

R5 is the earliest located assembly guide. R1-R4 and R9-R12 PDFs were not located in the previous inventory. R15/R16 are evidenced mechanical prototype changes, incorporated here without fictitious intermediate PDF/manual editions. Margin labels identify documentary changes, not physical test passes.

## 01 Current status and configuration

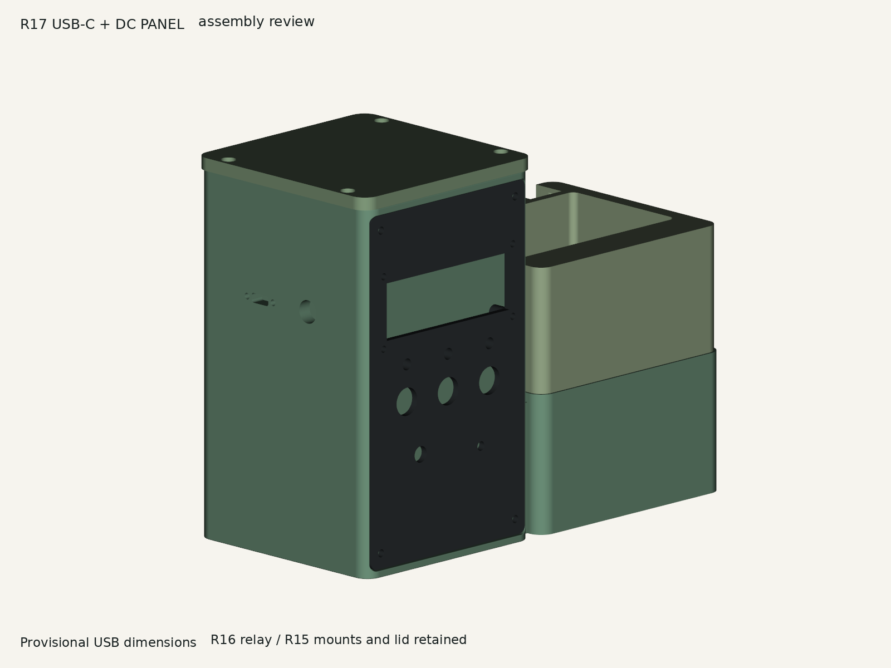
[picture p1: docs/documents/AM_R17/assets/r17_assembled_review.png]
Actual R17 exported geometry with retained R16 lid and R13 fascia/planter. Components are omitted; this image does not establish fit.


Actual R17 exported geometry with retained R16 lid and R13 fascia/planter. Components are omitted; this image does not establish fit.

Use this integrated R17 manual for the current prototype build. R15/R16 changes are incorporated here. It replaces R14 instructions for the current assembly, while the R14 documents remain historical evidence.
*Revision labels: R17; change IDs: T17-4.*

**CAUTION:** Prototype status: digital geometry is checked; physical screw, connector, relay, pump-route and leak acceptance remain open. Do not infer those passes from a rendered assembly.

Four main printed parts: R17 integrated body, R16 flush-head lid, R13 fascia and R13 planter. Select one knob variant. There is no separate battery tray or hose clip.
*Revision labels: R10, R13, R15, R17; change IDs: T10-1, T13-1, T15-2, T17-1.*

Terms: Confirmed = current file/check evidence; Reported = operator/source record; Assumed = explicit unmeasured geometry; Unknown = no adequate evidence; Not tested = no physical result. Firmware UI v6 is independent of design R17.

## 02 Printed parts and exact file selection

| Part / qty | File | Use / disposition |
| --- | --- | --- |
| M01 / 1 | tower_sump_body_uno_ports_r17.stl | R17 body; 207 x 100 x 158 mm |
| M02 / 1 | fascia_charcoal.stl (R13) | Retained front panel, nominal 12 mm button holes |
| M03 / 1 | top_cover_flush_r16.stl | R15 lid geometry; 99 x 100 x 5.5 mm; assembled top z163.5 |
| M04 / 1 | planter_sage.stl (R13) | Retained removable planter and two drains |
| M05 / 1 | One measured-shaft knob variant | Choose from R13 knob variants, not all eight |
| T01 / first | power_ports_fit_coupon_r17.stl | 6 thick x 60 x 24; print and fit USB and DC hardware |
| T02 / first | boss_trial_pilot_2p8.stl (R15) | Full-depth screw trial; 3.0 alternative only after recorded failure |
| T03 / first | lid_head_trial_r15.stl | Actual lid screw-head and seating trial |
| T04 / first | pump_route_trial_r15.stl | Actual pump plus attached tubing clearance |
| T05 / first | relay_mount_trial_r16.stl | Actual board, underside, screw and wire access trial |

**CAUTION:** Do not print an older tower or lid alongside this set. The R14 carrier coupon is superseded for the revised boss/pilot acceptance; the R13 ESP32 carrier coupon is not an Uno coupon. Retained dimensions do not close actual fit.

## 03 Hardware, electronics and incoming evidence

| Item / qty | Specification basis | Evidence / action |
| --- | --- | --- |
| Uno / 1 | Classic Uno R3, ATmega328P | Record actual clone/revision and four asymmetric holes |
| Uno screws / 4 | 2.8 x 11 blind pilot; screw dimensions unknown | Trial fastener family/length; do not force a fit |
| Relay / 1 + 4 screws | Nominal 50 x 26 PCB, 44.5 x 20.5 pitch, 3.1 holes | Photo/listing basis only; measure underside and holes |
| Lid / 4 screws | 3.4 through holes; 6.6 x 2.5 head pockets | Head/type/length unknown; use lid coupon |
| Fascia / 4 screws | Retained printed pilots | Prior 3 x 8 thread-forming allocation is provisional |
| LCD / 1 + 4 fixings | 16 x 2 I2C; 75 x 31 centres | Actual backpack/pin markings; M2.5 stack provisional |
| Buttons / 3 | Four-wire momentary illuminated buttons | Identify contacts, LED polarity and current limit separately |
| Potentiometer / 1 | A1 dose control; shaft/nut unknown | Verify terminals and select actual shaft-fit knob |
| USB-C / 1 + 2 screws | Image flange 20.1; PCB 9.1; depth 14.5 | Cut/pitch estimated; panel electrical interface open |
| DC extension / 1 | Requested 10 mm panel cut | Thread, nut, grip range, polarity and cable unknown |
| Pump / 1 + tubing | Separate supply reported 3.5 V | Rated voltage/current, envelope, outlet and tubing unverified |
| Probe / 1 | Installed 447 dry / 221 wet reference | Relative index; verify supply and installed probe |
| Sounder / optional | 10 mm case provision | Type/current unverified; no new wiring approved |
| Holder / optional | Integrated insulated-holder saddle | Cell/charger/power path not accepted; leave cell out |

Use callipers, multimeter, hand drivers, small spanners and appropriate insulated harness tools. Printer, material, layer settings, fastener torque and instrument calibration status are Unknown until recorded. Do not use a powered driver for the printed pilot trials.

## 04 Fit trials and print hold points

1. Print the R17 port coupon. Put its broad 60 x 24 face on the bed, with 6 mm thickness and hole axes vertical. Inspect the slicer orientation and record the resulting bore dimensions.
*Revision labels: R17; change IDs: T17-1.*

2. Fit USB-C and barrel hardware together: flange seats, mounting holes register, USB plug engages fully, DC nut/thread grip spans 6 mm, and both plug bodies and service leads clear. Stop on cracking, forcing or incomplete engagement.
*Revision labels: R17; change IDs: T17-1.*

3. Trial the actual Uno screw in the R15 2.8 mm coupon. Inspect splitting, bottoming, retention, screw projection and board contact. The 3.0 mm trial is an alternative investigation; the R17 body remains 2.8 mm until explicitly regenerated.
*Revision labels: R15; change IDs: T15-1.*

4. Trial lid heads, pump/tube route and four-hole relay registration in their matching coupons. Record the actual screw, component, print material and photographs. These tests can run independently.
*Revision labels: R15, R16; change IDs: T15-2, T15-3, T16-1.*

**CAUTION:** Full-body print hold: resolve failed coupon interfaces, update the CAD parameter/source, rebuild and recheck exports. Slicing, physical manufacturing and acceptance are separate from the supplied digital checks.
*Revision labels: R17; change IDs: T17-4.*

## 05 Uno and relay mounting; flush lid

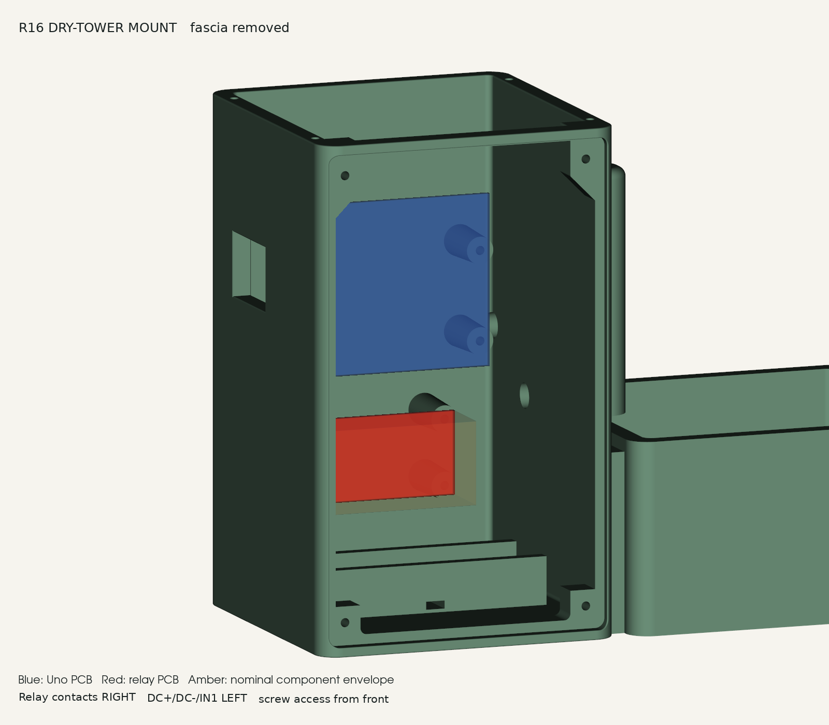
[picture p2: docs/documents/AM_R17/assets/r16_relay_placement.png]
R16 nominal PCB/component placement, retained inside R17. Proxies show approximate envelopes; this is not a fitted-hardware photograph.


R16 nominal PCB/component placement, retained inside R17. Proxies show approximate envelopes; this is not a fitted-hardware photograph.

Uno hole centres x/z: (79.75,107.56), (79.75,79.62), (28.95,122.80), (27.68,74.54). Seat plane y76; board faces the removable fascia. Register all four holes without bending the PCB.
*Revision labels: R14; change IDs: T14-1.*

Revised Uno bosses: 8.5 mm tip / 10.0 mm root, 19 mm projection, 2.8 mm nominal blind pilot 11 mm deep from the seat. This addresses the reported R14 splitting but retention and print strength remain untested.
*Revision labels: R15; change IDs: T15-1.*

Relay PCB x21-71 / z33-59, seat y76; contacts to the right, logic terminals left. Hole centres x/z: (23.75,35.75), (23.75,56.25), (68.25,35.75), (68.25,56.25). Bosses match the Uno cone/pilot profile. Check underside solder and actual wires before tightening.
*Revision labels: R16; change IDs: T16-1.*

Lid: 5.5 mm thick with 3.4 mm through holes and 6.6 mm diameter x 2.5 mm deep pockets. Nominal head bearing plane remains z161; top z163.5. Trial head height and engagement, then hand-seat all four screws without distortion.
*Revision labels: R15; change IDs: T15-2.*

## 06 Wet-side pump, tube and sensor routes

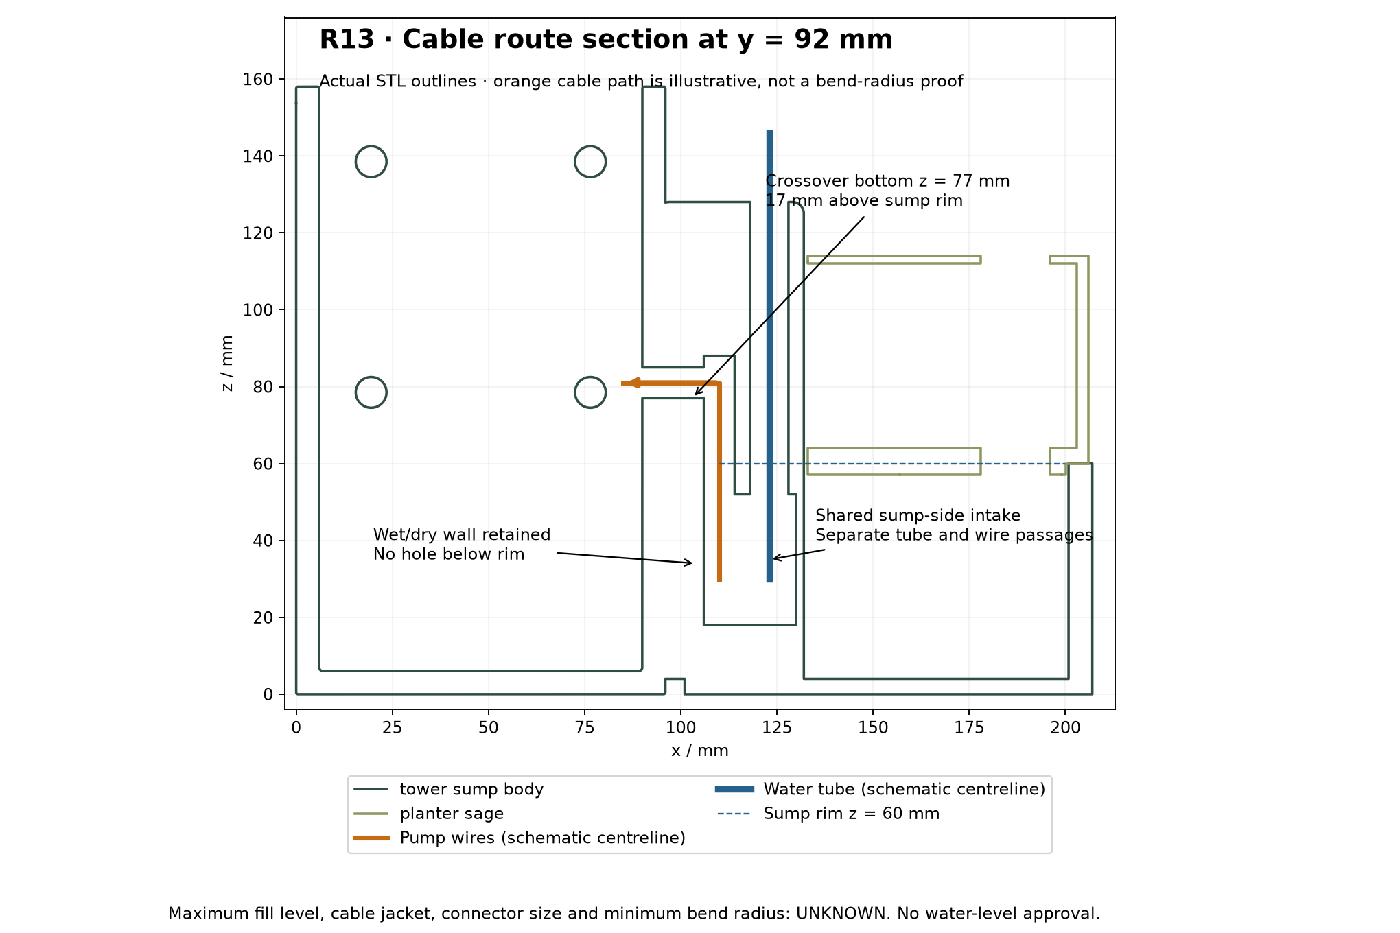
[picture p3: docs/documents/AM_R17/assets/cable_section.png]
Retained R13 route view: separate water tube and pump-wire passages. The lower pump relief is changed by R15; this historical route figure is not a complete R17 section.


Retained R13 route view: separate water tube and pump-wire passages. The lower pump relief is changed by R15; this historical route figure is not a complete R17 section.

With every supply disconnected, remove the planter and fit the actual pump with its tube attached. Reserved pump envelope 38.5 x 25.5 x 43 mm is a reference, not a measured supplied part.
*Revision labels: R6; change IDs: T06-1.*

Feed tube through the 10 mm bore at x123/y92. Feed pump leads through the separate 8 mm bore at x110/y92 and its elevated crossover. Keep the water tube outside the electronics cavity; provide real-part strain relief and respect its bend radius.
*Revision labels: R12; change IDs: T12-1.*

R15 lower relief is x106.5-132, y83-94, z4-52. Sump floor stays 4 mm. Check the actual outlet/tube against the pump-route coupon and assembled body; preserve the dry-side partition.
*Revision labels: R15; change IDs: T15-3.*

Sensor entry is diameter 8, centre y65/z64, lower edge z60. Use the planter service relief, a removable service loop and suitable abrasion/drip protection. Lower edge z60 is a geometric datum, not a fill mark.
*Revision labels: R13; change IDs: T13-4.*

Tie an identified insulated holder into the integrated saddle only if used; slot 6 x 2.5, prior tie assumption 4.8 x 1.5. Keep the locking head accessible and all contacts clear. No cell or charging circuit is accepted by this mechanical provision.
*Revision labels: R11; change IDs: T11-1.*

## 07 Left USB-C and barrel-extension panel

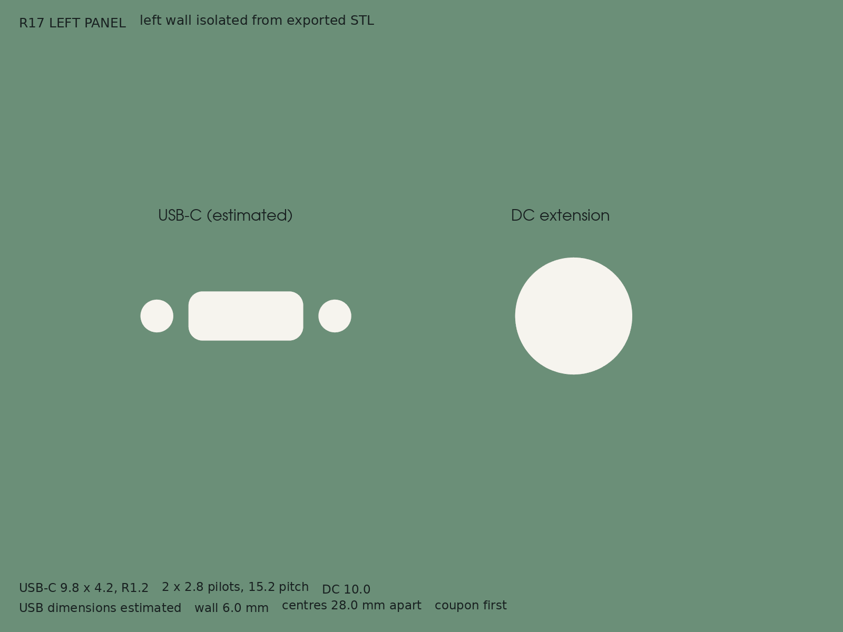
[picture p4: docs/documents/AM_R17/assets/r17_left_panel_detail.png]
Actual R17 left-wall mesh isolated at x <=6.01 to expose through-holes; other material is clipped for this view.


Actual R17 left-wall mesh isolated at x <=6.01 to expose through-holes; other material is clipped for this view.

| Interface | Dimension / position | Status |
| --- | --- | --- |
| USB cut | 9.8 x 4.2; corner radius 1.2; y63/z108.5 | Authorised estimate |
| USB pilots | 2 x diameter 2.8 through; 15.2 pitch | Diameter matches PCB pilot convention; pitch estimated |
| DC hole | Diameter 10.0; y35/z108.5 | User-specified; no added allowance |
| Wall / separation | 6 thick; centres 28 apart along y | Selected placement; actual nut/plug envelopes unmeasured |
| USB flange/PCB/depth | 20.1 / 9.1 / 14.5 | Image labels only; unmeasured actual part |

Mount the flange against the outside wall after the coupon passes. USB screws engage only the 6 mm wall, not an 11 mm blind boss; select length for the flange and check internal tips. Approximately 1.3 mm nominal material separates each pilot from the USB cut. Do not infer thread retention from the matching diameter.
*Revision labels: R17; change IDs: T17-1.*

**CAUTION:** Electrical hold: identify connector pins, USB-C configuration-channel termination, data/power route and DC extension polarity/rating before soldering the installed harness. The image's 6-pin/5 A label is not verified. The cut does not authorise a 9 V connection to USB or a new direct 5 V feed to the Uno.
*Revision labels: R17; change IDs: T17-5.*

## 08 Fascia components, harness and dry closure

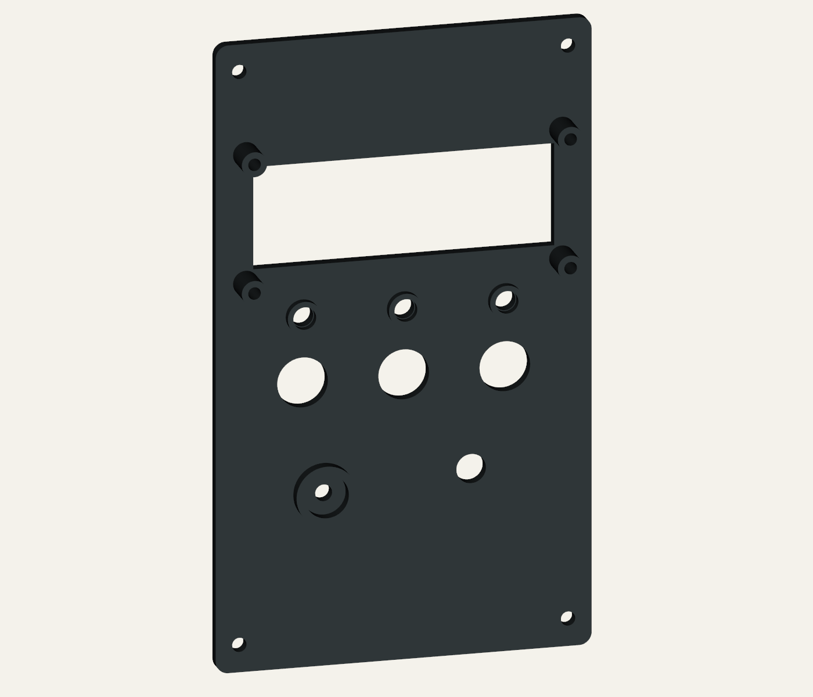
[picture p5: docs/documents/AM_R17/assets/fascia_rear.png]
Retained R13 fascia and mounting pads. Printed geometry is retained; current control colours/functions are defined by E02, not historical artwork.


Retained R13 fascia and mounting pads. Printed geometry is retained; current control colours/functions are defined by E02, not historical artwork.

Fit the LCD to the 75 x 31 mm pattern behind the 71.4 x 24.6 aperture. Trial the actual fixings, head diameter and backpack stack; no PCB bowing or contact with screw tips.
*Revision labels: R7; change IDs: T07-2.*

Fit the green WATER, yellow NEXT/LAMP TEST and red STOP momentary buttons with their matching nuts. Verify nominal 12 mm holes against real hardware. Fit the potentiometer and select one shaft-fit knob; leave at least 0.5 mm axial clearance. No millilitre scale is valid until measured flow calibration.
*Revision labels: R8, R17; change IDs: T08-4, T17-2.*

The retained sound port/seat and LED collars are mechanical provisions. If used, apply compatible adhesive around case perimeters only; keep light surfaces, sound opening and conductors clear. Electrical type/rating remains unverified.
*Revision labels: R8; change IDs: T08-3.*

Install labelled service loops and insulated joints clear of fasteners. Keep relay contact/pump leads separate from sensitive LCD/probe routes where practicable. Fit fascia, lid and planter by hand; confirm no trapping and full planter removal. No validated screw torque is supplied.

## 09 E01 - LCD, soil probe and dose potentiometer

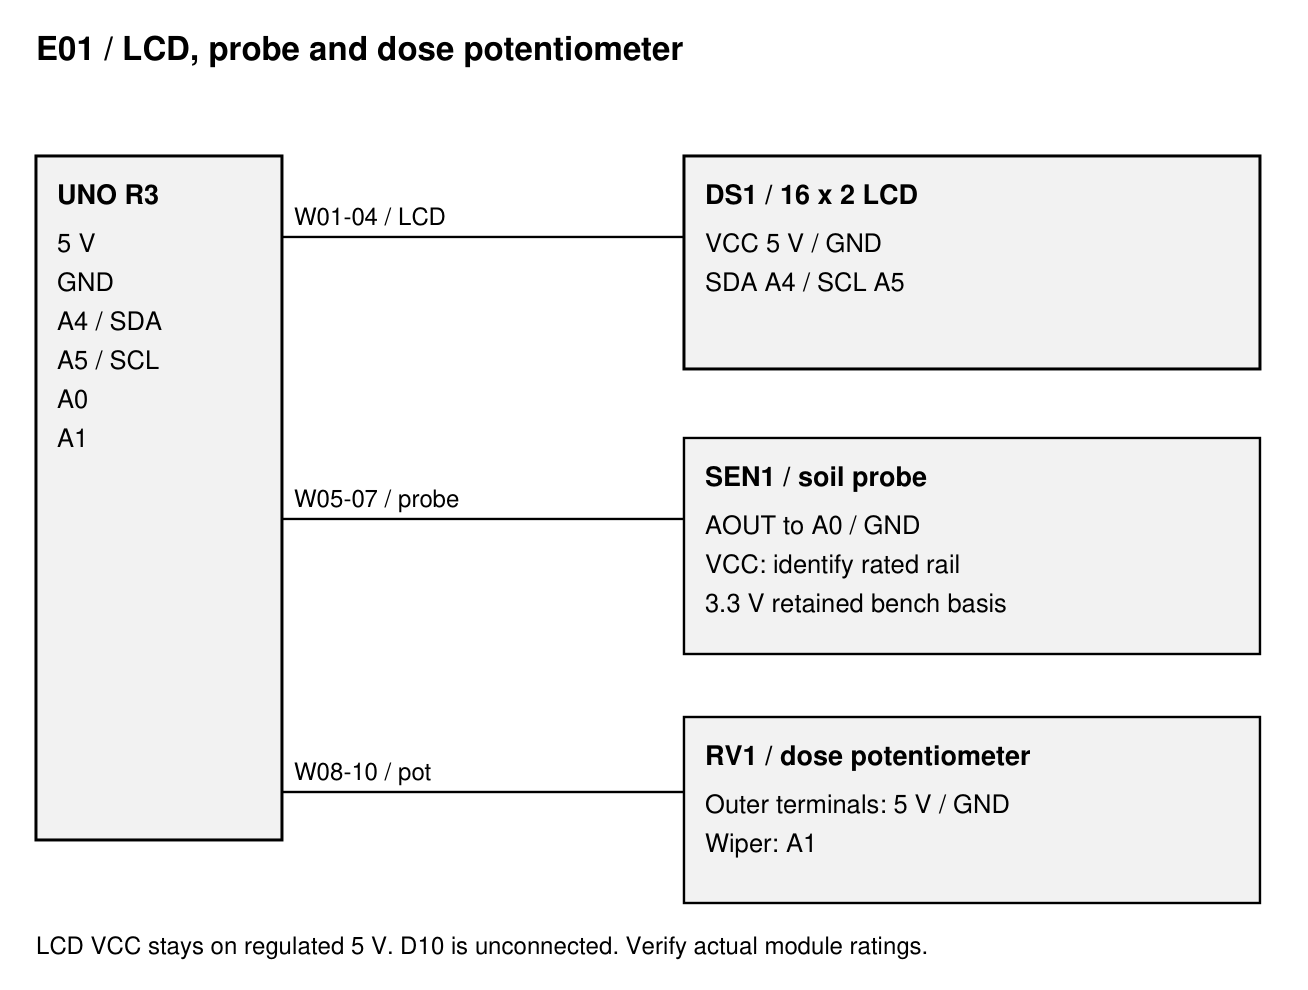
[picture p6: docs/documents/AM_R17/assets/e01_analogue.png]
Current logical route from the recorded Uno interface. Wiring is conditional on identified component ratings; shared return is a branch network, not a series chain.


Current logical route from the recorded Uno interface. Wiring is conditional on identified component ratings; shared return is a branch network, not a series chain.

LCD VCC to regulated Uno 5 V; GND to GND; SDA to A4; SCL to A5. D10 is unconnected. Backlight control uses the I2C backpack while LCD logic stays powered.
*Revision labels: R17; change IDs: T17-2, T17-3.*

Soil AOUT to A0 and dose-pot wiper to A1. Retained probe bench basis is 3.3 V subject to the actual sensor rating; current supply continuity has not been re-measured. Pot outer terminals use 5 V and GND; verify direction and terminals before connection.
*Revision labels: R17; change IDs: T17-2.*

**CAUTION:** Keep pump supply OFF for all logic, upload and LCD checks. Repair intermittent LCD initialisation/write failures before treating the displayed pages as accepted.

## 10 E02 - buttons, LEDs and numbered signal schedule

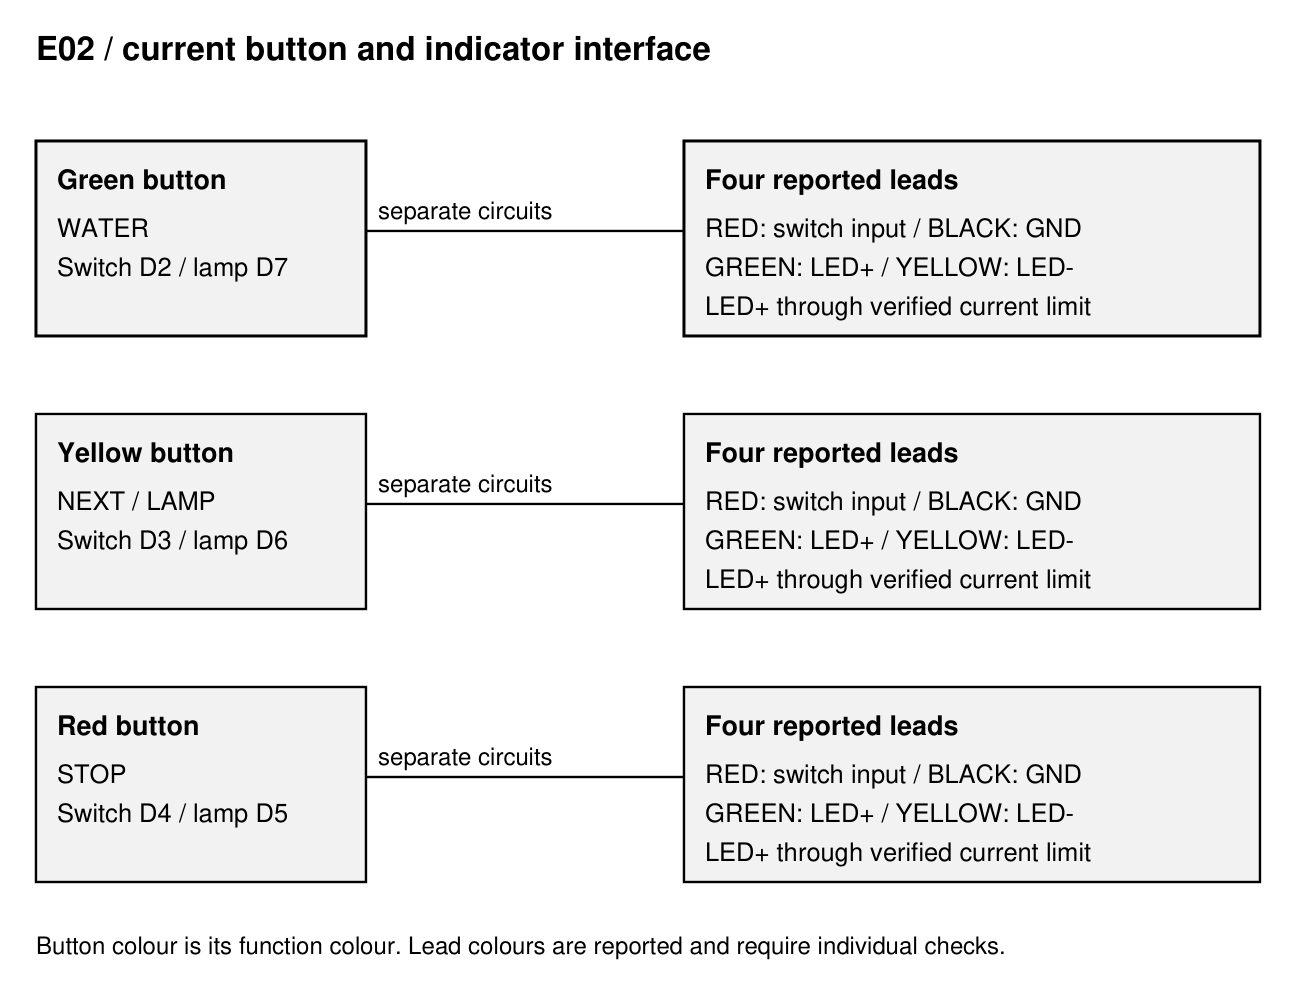
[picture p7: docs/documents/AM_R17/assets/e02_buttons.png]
Function colour and reported lead colour are different attributes. Continuity/polarity must be confirmed for each physical button.


Function colour and reported lead colour are different attributes. Continuity/polarity must be confirmed for each physical button.

| Wires | From / to | Required identification |
| --- | --- | --- |
| W11 / W12 | D2 / GND -> green WATER switch | Reported red / black leads; INPUT_PULLUP |
| W13 / W14 | D3 / GND -> yellow NEXT/LAMP switch | Reported red / black leads; INPUT_PULLUP |
| W15 / W16 | D4 / GND -> red STOP switch | Reported red / black leads; INPUT_PULLUP |
| W17 / W18 | D5 via limit / GND -> red lamp | Reported green LED+ / yellow LED- |
| W19 / W20 | D6 via limit / GND -> yellow lamp | Reported green LED+ / yellow LED- |
| W24 / W25 | D7 via limit / GND -> green lamp | Reported green LED+ / yellow LED- |
| W23 / W26 | D9 / logic GND -> relay IN1 / GND | Actual terminal labels and trigger current to verify |

**CAUTION:** Each lamp needs its own verified current-limiting arrangement. The old R14 1 kOhm bare-LED example does not qualify the purchased illuminated buttons. Identify built-in limiting or select the external resistor from the actual LED evidence.
*Revision labels: R17; change IDs: T17-2.*

## 11 E03 - relay and complete supply schedule

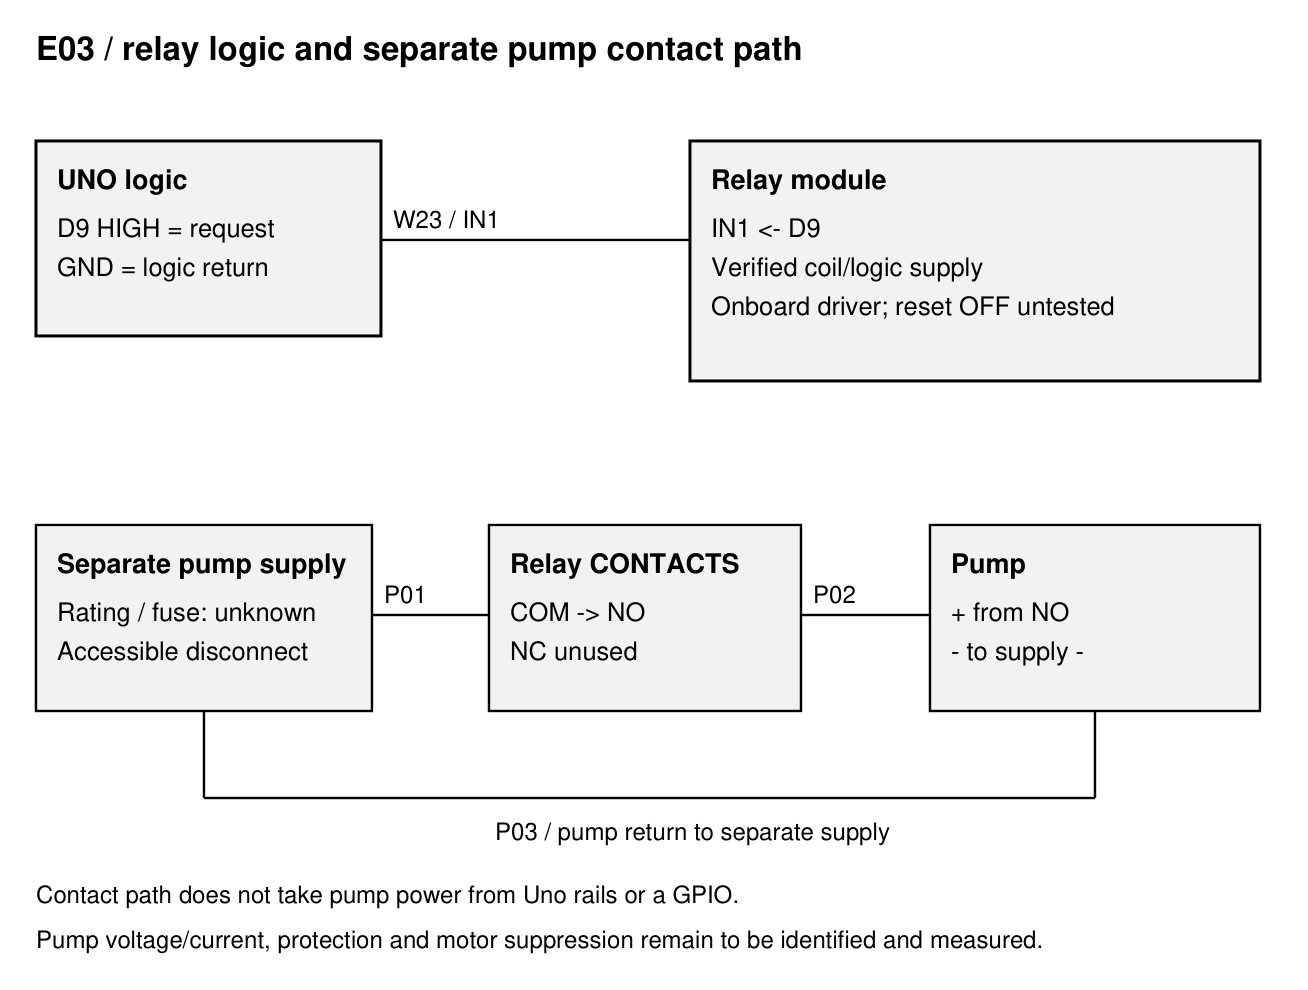
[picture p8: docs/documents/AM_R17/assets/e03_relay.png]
Logical relay and separate pump supply route. This is not a selected fuse, wire-size, contact-rating or suppression design.


Logical relay and separate pump supply route. This is not a selected fuse, wire-size, contact-rating or suppression design.

| Wire IDs | Connection | Disposition |
| --- | --- | --- |
| W01-04 | 5 V / GND / A4 / A5 -> LCD | As identified backpack markings |
| W05-07 | Rated probe rail / GND / AOUT-A0 | Prior bench 3.3 V; confirm actual rating |
| W08-10 | 5 V / GND / wiper-A1 -> pot | Verify outer terminals and direction |
| W21 / W22 | Uno 5 V / GND -> distribution | Record branch continuity and total logic load |
| W27 / W28 | Verified relay supply / GND -> module | Coil/input current and supply source unmeasured |
| P01 | Pump supply + -> fuse/disconnect -> COM | Supply/fuse/contact rating requires measurement |
| P02 / P03 | NO -> pump + / pump - -> supply - | Pump separate from Uno rails; NC unused |

D9 is active HIGH in the current source; LOW at normal idle. During reset/bootloader it is high impedance. Measure relay OFF across reset and supply ordering, input current and contact state; provide a proven external default-OFF arrangement if necessary.
*Revision labels: R17; change IDs: T17-2.*

**CAUTION:** STOP cancels the software request. It cannot isolate a welded relay contact or a failed controller. Keep an accessible physical pump-power disconnect and rated protection. Identify the actual motor and suppression before a powered trial.

## 12 USB and barrel extension - open electrical interface

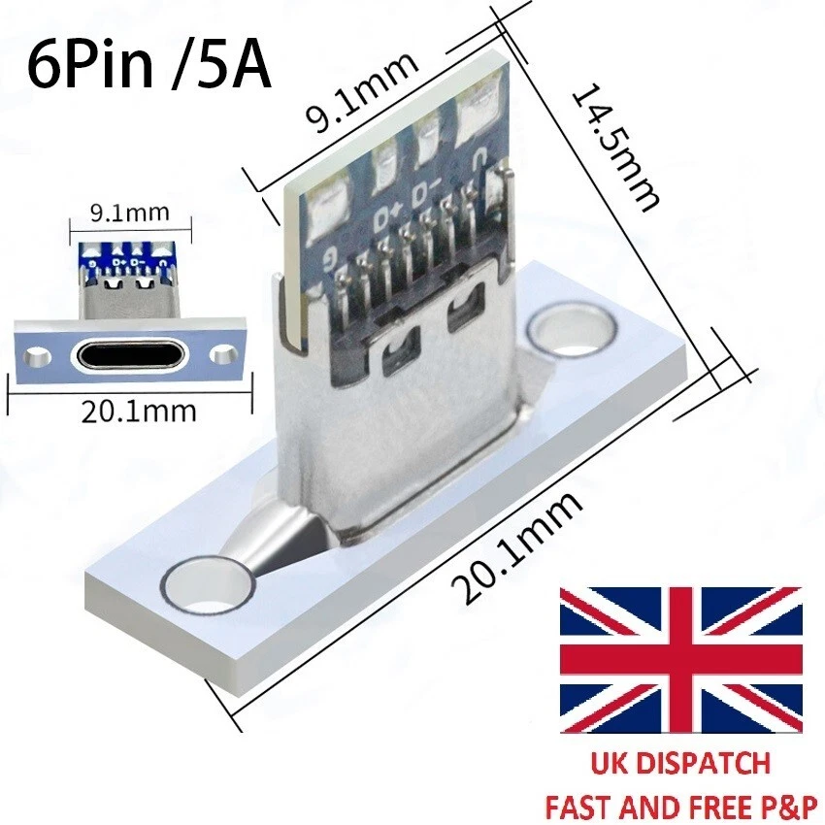
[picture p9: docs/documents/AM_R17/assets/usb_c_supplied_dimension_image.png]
Original user-supplied component image. Labelled geometry is reference evidence; its seller rating and pin functions have not been independently qualified.


Original user-supplied component image. Labelled geometry is reference evidence; its seller rating and pin functions have not been independently qualified.

The R17 cuts support the intended alternative USB and Uno barrel-input connections. No USB-C solder pin mapping, cable adaptation or DC plug selection is approved by this document. Use the identified onboard USB connection for dry bench checks until A17-07 closes.
*Revision labels: R17; change IDs: T17-5.*

| Required evidence | Close A17-07 by recording |
| --- | --- |
| USB component identity | Exact variant, connector pin map and measured shell/flange/fixing dimensions |
| USB power/data route | Continuity, configuration-channel termination, intended data capability and supply compatibility |
| Barrel extension | Actual mating sizes, polarity continuity, rated cable/current and 6 mm panel grip |
| Supply arrangement | Selected voltage for each board input, regulation/load evidence and intended one-source procedure |
| Acceptance | Measured idle/load rails, no unwanted source coupling, insulated strain relief and retained wiring diagram |

Owner: Unassigned. Target: Not set. Do not assume the phrase '9 V battery connection' specifies the purchased extension, its polarity or an accepted supply.

## 13 Firmware identity and operator behaviour

Frozen electrical reference: PlantUno UI v6 for arduino:avr:uno. The supplied source enables RELAY_ENABLED=true and ActiveHigh on D9, with 1,000-4,000 ms request limits, sampled from A1 at WATER start. This manual does not upload or change firmware.
*Revision labels: R17; change IDs: T17-2, T17-3.*

| Control / state | Current source behaviour | Physical evidence |
| --- | --- | --- |
| Green WATER | One bounded request; knob sampled once; release does not cancel | Actual duration/volume not measured |
| Yellow button | Idle pages Status/Raw/Session; hold lamp test; cancels dose | Full pages and lamp behaviour open |
| Red STOP | Cancels; release required to re-arm; hold 2 s clears volatile counters | Software cancellation, not isolation |
| Moisture | Below 25% red blink; at/above 25% green; 500 ms stability | Relative calibrated index, not volumetric moisture |
| A0 raw <=20 | Fault indication; green OFF; CHECK SOIL A0 | Fault classification is not a pump interlock |
| Pump request ends | Immediate soil Status return; sensor fault remains explicit | Post-dose physical screen observation open |
| Backlight | 60 s idle off; buttons or >=8 ADC knob counts wake; pump stop restarts timer | Serial OFF/ON recorded; visual and post-dose timer open |

The 27 September upload record reports COM8, 14,950 flash bytes and 870 global RAM bytes. Current frozen source hash matches that record. LCD status 0 and serial idle-OFF/activity-ON were recorded; previous LCD faults remain unresolved. These are historical records, not new tests performed for this manual.
*Revision labels: R17; change IDs: T17-4.*

**CAUTION:** Re-detect the board/port if uploading later; obtain confirmation that the separate pump supply is OFF. Keep the two header files with the sketch and use the correct board profile. No sensor state initiates automatic watering.

## 14 Dry commissioning and stop criteria

Use PLANT-TS-001 R17 D02 for actual results. All supplies remain disconnected during continuity, contact, screw and strain-relief inspections. Pump supply stays OFF for powered logic and display checks.

Verify each switch pair open/released and closed/pressed, each lamp polarity/limiting, LCD wiring and probe/pot connections. Record actual parts and voltages. Stop on uncertain pin labels, current limits or supply polarity.
*Revision labels: R17; change IDs: T17-2.*

With pump supply OFF, confirm serial identity, relay request OFF at idle, stable LCD status 0 and no write failures. Check all three switches, page navigation, lamp test, STOP/release, A1 endpoints, 25% indications and the rail-low fault using a safe identified test arrangement.
*Revision labels: R17; change IDs: T17-3.*

Observe 60 s backlight idle-off and button/knob wake; separately observe full 60 s after completed/cancelled requests. Confirm the soil Status page returns immediately on request end. Serial acknowledgement alone does not accept the actual LCD.
*Revision labels: R17; change IDs: T17-3.*

**CAUTION:** Stop on an unexpected relay contact closure, LCD fault, overheating, loose wiring, damaged printed support or trapped service lead. Record the defect and keep affected power isolated until corrected.

## 15 Wet acceptance, operation and care

Electrical/pump acceptance, material qualification and leak/fill testing are prerequisites for supervised wet trials. Define the method, maximum fill candidate and duration before recording a pass. No accepted fill volume exists here.

With electronics removed or independently protected, test the actual printed sump for leakage and inspect dry boundaries. Verify drain-back headspace, both planter drains, riser behaviour, tube retention and splash/tilt ingress. Sensor lower edge z60 and sump rim are not approved fill marks.
*Revision labels: R13; change IDs: T13-4.*

After ratings/protection/default-OFF checks, measure separate-supply pump contact timing and delivery at 1.0 and 4.0 s settings with the installed lift and tube. Define allowable duration/volume error from the intended requirement; those tolerances are not yet set.
*Revision labels: R17; change IDs: T17-4.*

Before each accepted supervised use inspect water, tube, drains, visible leaks and supply leads. Isolate all power before moving, cleaning or removing the planter. Empty before moving and support the complete base; do not immerse the electronics tower.

Remove soil debris from both drains and pump inlet. Use cleaning materials and temperature limits compatible with the qualified print material. No unattended-operation approval or water-ingress rating is claimed.

## 16 Build record, open actions and source map

| Build field | Actual recorded value |
| --- | --- |
| Build ID / operator / date | ________________ / Unknown |
| Actual PCB / relay / pump identities | ________________ / Unknown |
| Printer / material / slicer / saved job | ________________ / Unknown |
| STL hash / source issue / orientation | ________________ / Unknown |
| Fastener family / measured dimensions | ________________ / Unknown |
| USB/DC component and wiring evidence | ________________ / Unknown |
| Physical fit / leak / fill evidence | ________________ / Unknown |
| Duration / volume results and tolerances | ________________ / Unknown |
| Defects / deviations / action closure | ________________ / Unknown |
| Reviewer / date / disposition | ________________ / Unknown |

A17-01 through A17-13 are the shared acceptance IDs in PLANT-TS-001. Owner: Unassigned; targets: Not set. Blank fields are Unknown, never passes. Record evidence and explicit disposition before closing an action.
*Revision labels: R17; change IDs: T17-4.*

Sources: R13 retained CAD/readme; R14 Uno mounting evidence; R15 DESIGN_REVIEW and verification; R16 REVIEW and verification; R17 parameters, checks and attached image; current Uno sketch/headers; 27 September interface/upload record. The package contains frozen source copies, SHA-256 register and selected printable files.

Change bars use the verified control matrix. R17 electrical bars mean newly incorporated manual content from 27 September; they do not claim that UI v6 originated in the 28 September mechanical revision. R1-R4 and absent intermediate PDF editions remain undocumented.

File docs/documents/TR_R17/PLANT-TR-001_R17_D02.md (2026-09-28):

# Plant Station R17 - Design Review

**PLANT-TR-001 / R17 / D02 / 28 September 2026**

Issued for prototype review; physical acceptance open

Current mechanical configuration: R17 integrated body, R16 lid (R15 geometry), R13 fascia and planter. Electrical reference: frozen Uno UI v6 source and 27 September interface record. Fit, powered wet operation and unattended operation remain unaccepted.

## Revision control

- R5-R13 / source history: Earlier assembly and mechanical changes remain traceable through the preserved D01 matrix. Missing document editions are not invented.
- R14 / preceding manual: AM R14 D01: Uno mounting and motor-disabled bench v2. TR's latest located same-family PDF is R13 D01; no TR R14 PDF is assumed.
- R15 / 27 Sep 2026: Reinforced Uno bosses, thicker recessed-head lid and additional pump relief; source changes incorporated at R17, physical trials open.
- R16 / 27 Sep 2026: Four relay bosses below Uno; source change incorporated at R17; actual underside and hole pitch unmeasured.
- UI v6 / 27 Sep 2026: Three buttons and integrated lamps, enabled active-HIGH relay, 1-4 s request, soil display and 60 s backlight timeout. Firmware revision is independent of mechanical R17.
- R17 / 28 Sep 2026: Mounted USB-C cut and pilots, adjacent diameter 10 DC extension hole; estimated dimensions authorised; coupon fit required.
- D02 / 28 Sep 2026: Integrated current R17 document issue. Uses the established enhanced template, controls and cumulative revision bars. No R15/R16 manual issues created.

R5 is the earliest located assembly guide. R1-R4 and R9-R12 PDFs were not located in the previous inventory. R15/R16 are evidenced mechanical prototype changes, incorporated here without fictitious intermediate PDF/manual editions. Margin labels identify documentary changes, not physical test passes.

## 01 Current state and incorporated changes

Actual assembled STL review; electronic hardware omitted.

Actual assembled STL review; electronic hardware omitted.

R17 incorporates R14 Uno registration, R15 splitting/lid/pump rectifications, R16 relay mounting and the R17 two-port panel. Current firmware scope is Uno UI v6. Digital geometry is available for prototype trials; physical fit and powered wet acceptance remain open.
*Revision labels: R17; change IDs: T17-4.*

R14 was the reported printed baseline. Its Uno supports split during screw insertion. The user requested a thicker recessed-head roof and removal of the pump/tube obstruction; R15 records these changes. Screw dimensions, printed material and causal strength evidence are still absent.
*Revision labels: R15; change IDs: T15-1, T15-2, T15-3.*

This is the next located design-review document after TR R13 D01. R14-R16 geometry/evidence is incorporated without asserting missing same-family PDFs. R17 documents supersede their current assembly instructions, not the retained historical evidence.

## 02 Known constraints and configuration contract

| Interface | Current basis | Evidence status |
| --- | --- | --- |
| Body | 207 x 100 x 158; integrated tower/sump | Confirmed export bounds |
| Lid | 99 x 100 x 5.5; top z163.5 | Confirmed retained R15/R16 CAD |
| Uno | Four asymmetric R14 centres; y76 seat | Source-verified; actual variant fit open |
| Bosses | 8.5 tip / 10 root / 19 projection; 2.8 x 11 pilot | Prototype; physical screw fit open |
| Relay | 50 x 26 PCB; 44.5 x 20.5 pitch | Seller/photo nominal; underside unknown |
| USB panel | 9.8 x 4.2 R1.2, 2.8 pilots at 15.2 pitch | Authorised best guesses |
| DC panel | Diameter 10; centre 28 from USB | User hole size; nut/grip unknown |
| Wet route | 4 floor; separate tube/wire paths; sensor edge z60 | Geometry checked; no fill limit |

Preserve the wet/dry partition, planter serviceability, fascia interface and asymmetric board registration. Physical hardware measurements outrank the provisional proxy dimensions. No new firmware modification is included in R17 documentation.

## 03 Mount, lid and pump options

| Feature | Options and trade-off | Selected prototype / gate |
| --- | --- | --- |
| Uno mount | Thicker/tapered bosses retain four-screw assembly; inserts/captive nuts improve repeated service but need new fit/access data | R15 reinforced bosses retained. Coupon required; splitting cause is unproven |
| Lid | Thicker pocketed lid gives flush heads; unchanged thin roof preserves old shape but misses request | R15 5.5 thick, 6.6 x 2.5 pockets; head/engagement trial |
| Pump route | Rotate pump may avoid relief but restrict service; lower local relief removes reported ledge | R15 relief x106.5-132/y83-94/z4-52; actual attached tube trial |
| Relay placement | Vertical below Uno consumes nominal height; side wall conflicts with access; rear-wall horizontal gives service space | R16 horizontal, 12 mm above saddle and 13 below Uno; terminal/wire fit open |

Recommendation: retain the selected R15/R16 geometry for representative trials. Do not switch fastener architecture or widen pilots in the body without actual trial evidence and regenerated exports. Fit and retention are separate from digital solid validity.

## 04 USB-C and barrel panel decision

Left-wall mesh detail; both openings are at z108.5.

Left-wall mesh detail; both openings are at z108.5.

| Option | Benefit | Trade-off |
| --- | --- | --- |
| Integral wall cuts (selected) | Matches requested fixed panel; no extra printed part | Estimated USB fit and 6 mm DC grip must pass coupon |
| Replaceable connector insert | Easier later adjustment to another USB/DC component | Adds fastening, seams and another controlled part |
| Retain broad cable opening | Accepts direct original cable access | Does not implement requested fixed sockets |

The user requested the fixed USB/DC panel and explicitly authorised best guesses with PCB-sized holes. Integral wall cuts are selected for this prototype. USB shell cut 9.8 x 4.2 R1.2; pilots 2.8 through at 15.2 pitch; DC diameter 10. USB y63, DC y35, common z108.5.
*Revision labels: R17; change IDs: T17-1.*

Estimated pilot-to-cut material is 1.3 mm. Image flange width 20.1 gives 12.95 mm to the DC cut; a guessed diameter-20 nut would leave 7.95 mm. These calculations depend on unmeasured component envelopes and do not establish fit or strength.
*Revision labels: R17; change IDs: T17-1.*

**CAUTION:** Recommendation: coupon both actual connectors together, including mating plugs, nut grip, screw tips and solder service. Keep the electrical pin/power interface open until characterised; no USB-C rating or source behaviour follows from the cut.
*Revision labels: R17; change IDs: T17-5.*

## 05 Electrical and firmware configuration impact

R14 disabled-motor bench v2 and spare third switch are historical. Current source enables active-HIGH D9 relay requests and uses D2/D3/D4 switches; D5/D6/D7 red/yellow/green lamps. A4/A5 serve LCD; A0/A1 serve probe/pot; D10 is unused.
*Revision labels: R17; change IDs: T17-2.*

Dose requests are 1-4 s, knob sampled once. Yellow cycles pages/holds lamp test/cancels; STOP cancels and two-second hold clears session counters. Sensor is advisory; below 25% red blink, at/above green, raw <=20 fault. Software STOP and sensor fault do not provide hardware isolation.
*Revision labels: R17; change IDs: T17-3.*

UI v6 commands soil Status return at request end and I2C backlight off after 60 s idle, waking on buttons or >=8 ADC pot-count change. Serial OFF/ON and LCD status 0 were recorded on 27 September; earlier communication failures and visual/post-dose checks remain open.
*Revision labels: R17; change IDs: T17-3, T17-4.*

**CAUTION:** Relay module/pump rating, current, supply behaviour and reset default-OFF are unmeasured. USB-C pins/configuration and barrel polarity/grip are unresolved. CAD provision does not accept a new power system. Keep a physical pump disconnect.

## 06 Evidence and digital verification limits

| Evidence | Recorded result | Limit |
| --- | --- | --- |
| R15 independent checker | Six final meshes/sections passed | Fastener, pump and leak physical gates open |
| R16 independent checker | Three single-component meshes and relay sections passed | Nominal board envelope only; underside unmeasured |
| R17 STEP/readback | Both exports reopened as one valid solid | Builder process still exits 1 on shutdown |
| R17 independent STL | Two closed consistently wound meshes; all edges two-face; no degenerate faces | Full mesh self-intersection not checked |
| R17 sections | Six wall sections: USB 9.800 x 4.200, DC approx 9.998 centre section, pilots approx 2.800 | Tessellated mesh dimensions; not printed-hole readings |
| R17 change scope | 0 added/removed mm3 outside left-wall mask | Does not establish physical insertion or strength |
| UI v6 source and record | Current SHA-256 matches 27 September upload record | No new hardware run in this documentation task |

Nominal module proxies have zero digital interference with the body/board proxies. Actual component fronts, solder, plug bodies and service loops are not represented accurately enough for physical acceptance. No slicing, physical print, continuous swept-lift or wet test is claimed.

## 07 Risks, unknowns and closure actions

| ID / type | Condition and effect | Mitigation / closure |
| --- | --- | --- |
| RI17-01 / Issue | USB cut/pitch and jack grip unmeasured; mismatch could require a body reprint | A17-01 coupon plus actual measurements |
| RI17-02 / Issue | Reported R14 boss splitting; R15 reinforcement physically untested | A17-02 screw/material/orientation trial; inspect root and tip |
| RI17-03 / Risk | Relay solder/terminals and fascia services may collide | A17-05/06 full assembled dry fit and removal trial |
| RI17-04 / Issue | LCD intermittent communication faults; screen may fail under load | A17-09 supply/I2C/suppression investigation and repeat observations |
| RI17-05 / Risk | Relay closure through boot/reset or welded contacts may leave pump running | A17-08 measured default-OFF; physical disconnect |
| RI17-06 / Issue | Fill/leak/material limits unknown; ingress into electronics possible | A17-11/12 material qualification and controlled leak/drain-back/splash evidence |
| RI17-07 / Issue | USB/barrel wiring and rating unresolved | A17-07 identified source diagram, continuity and load evidence |
| RI17-08 / Issue | CAD exit code 1 prevents a clean-build claim | A17-13 isolate shutdown cause or retain explicit exception |

Risk ratings are qualitative; no likelihood/severity matrix was supplied. All owners are Unassigned, target dates Not set, and all entries remain Open. USB guesses, relay nominal dimensions, screw torque, printer/material, supply/load limits and acceptance tolerances remain Unknown or Assumed as identified.

## 08 Acceptance recommendation and next actions

1. Print and fit the R17 port coupon; in parallel complete the matching Uno, lid, pump and relay trials. Record measurements and photographs. 2. Correct failed dimensions and re-export only affected geometry. 3. Complete full-body slicing review and dry serviceability fit. 4. Close the electrical interface and relay default-OFF evidence before supervised powered testing. 5. Close leak/fill and dose-volume evidence before accepted supervised wet use.
*Revision labels: R17; change IDs: T17-4.*

PLANT-TS-001 contains testable A17-01 to A17-13 records. A recommendation is not an acceptance signature. Current disposition: prototype review; digital evidence recorded; physical/electrical acceptance open.

References are frozen in the package evidence register. Prior enhanced D01 scheme/matrix is retained alongside the extended R17 change matrix. No R15/R16 manual issues or missing early PDFs were created.

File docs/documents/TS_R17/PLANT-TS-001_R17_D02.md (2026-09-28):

# Plant Station R17 - Test and Acceptance Sheets

**PLANT-TS-001 / R17 / D02 / 28 September 2026**

Issued for prototype review; physical acceptance open

Current mechanical configuration: R17 integrated body, R16 lid (R15 geometry), R13 fascia and planter. Electrical reference: frozen Uno UI v6 source and 27 September interface record. Fit, powered wet operation and unattended operation remain unaccepted.

## Revision control

- R5-R13 / source history: Earlier assembly and mechanical changes remain traceable through the preserved D01 matrix. Missing document editions are not invented.
- TS family / D02: PLANT-TS-001 assigned for this test-sheet set. Prior tests are source evidence; no earlier same-family controlled test-sheet issue is asserted.
- R15 / 27 Sep 2026: Reinforced Uno bosses, thicker recessed-head lid and additional pump relief; source changes incorporated at R17, physical trials open.
- R16 / 27 Sep 2026: Four relay bosses below Uno; source change incorporated at R17; actual underside and hole pitch unmeasured.
- UI v6 / 27 Sep 2026: Three buttons and integrated lamps, enabled active-HIGH relay, 1-4 s request, soil display and 60 s backlight timeout. Firmware revision is independent of mechanical R17.
- R17 / 28 Sep 2026: Mounted USB-C cut and pilots, adjacent diameter 10 DC extension hole; estimated dimensions authorised; coupon fit required.
- D02 / 28 Sep 2026: Integrated current R17 document issue. Uses the established enhanced template, controls and cumulative revision bars. No R15/R16 manual issues created.

R5 is the earliest located assembly guide. R1-R4 and R9-R12 PDFs were not located in the previous inventory. R15/R16 are evidenced mechanical prototype changes, incorporated here without fictitious intermediate PDF/manual editions. Margin labels identify documentary changes, not physical test passes.

## 01 Test article, prerequisites and recording rules

Test article: one R17 prototype using the controlled selected print files and frozen Uno UI v6 source. This sheet set defines future physical tests; it records no new physical passes. Link each action to a build ID, source hash, operator/date, actual configuration and retained evidence.
*Revision labels: R17; change IDs: T17-4.*

| Record field | Actual value |
| --- | --- |
| Build ID / serial / operator / date | ________________ |
| Printed-part hashes / document issue | ________________ |
| Printer / material / slicer / orientation | ________________ |
| Component models/revisions and photographs | ________________ |
| Screw measurements / engagement | ________________ |
| Supply identifiers / ratings / protections | ________________ |
| Instruments and calibration/check status | ________________ |
| Test method / environmental conditions | ________________ |
| Deviation IDs / defect report / evidence location | ________________ |

**CAUTION:** Before electrical work disconnect every supply. Before powered logic/upload checks confirm the separate pump supply is OFF. No upload, printer operation or powered test is executed by this document.

Use Pass / Fail / Not tested / Deferred with evidence. A blank actual result remains Not tested. Acceptance tolerances not supplied must be agreed and recorded before assessing that test; do not invent acceptable duration, volume, torque or leak rates.

## 02 Mechanical coupons and dry assembly

| Action ID | Test | Expected acceptance | Existing status |
| --- | --- | --- | --- |
| A17-01 | USB/DC fit coupon | USB shell and screw pattern fit; plug engages; DC thread/nut span 6 mm; no cracks | Not tested |
| A17-02 | Uno screws and board | 2.8 pilot trial takes actual screws; all four centres register without PCB bowing | Not tested |
| A17-03 | Flush lid | Heads sit flush/below surface; pockets intact; lid seats; engagement verified | Not tested |
| A17-04 | Pump route | Actual pump/tube clear relief; no kink; dry partition preserved | Not tested |
| A17-05 | Relay fit | Four-hole registration; solder, screws, terminals and service removal clear | Not tested |
| A17-06 | Fascia and full dry build | LCD/buttons/pot fit; wiring untrapped; planter lifts clear; all fasteners retain | Not tested |

A17-01: print the port coupon in the intended material; measure both mounting centres and each cut; trial connectors, fasteners, actual plugs, DC nut and solder/wire access together.
*Revision labels: R17; change IDs: T17-4.*

A17-02: trial actual screws in full-length 2.8 mm bosses; measure engagement and remaining pilot-depth margin. Inspect splitting/retention and all four Uno holes before approving a body change.
*Revision labels: R17; change IDs: T17-4.*

A17-03/04: trial actual lid heads and pump with attached tube against matching coupons, then check seat, clearances, removal and dry boundary in the body.
*Revision labels: R17; change IDs: T17-4.*

A17-05/06: measure relay hole pitch/underside; fit all four screws. Dry-build fascia, boards, wiring and planter; inspect tool access, contact/solder clearance and full removal travel.
*Revision labels: R17; change IDs: T17-4.*

| Action ID | Actual result / evidence | Verdict / operator / date |
| --- | --- | --- |
| A17-01 | ________________________ | Not tested / __________ |
| A17-02 | ________________________ | Not tested / __________ |
| A17-03 | ________________________ | Not tested / __________ |
| A17-04 | ________________________ | Not tested / __________ |
| A17-05 | ________________________ | Not tested / __________ |
| A17-06 | ________________________ | Not tested / __________ |

Owner: Unassigned. Target date: Not set. Deviations and corrective action: ____________________. Retest configuration/evidence: ____________________.

## 03 Power interface and relay reset acceptance

| Action ID | Test | Expected acceptance | Existing status |
| --- | --- | --- | --- |
| A17-07 | USB/barrel electrical interface | Exact USB pins/CC/power/data, DC polarity/voltage and source behaviour identified | Open design hold |
| A17-08 | Relay default OFF | Coil/input/contact ratings recorded; OFF through reset and both supply sequences | Not tested |

A17-07: identify USB-C part/pins and intended power/data adaptation; inspect configuration-channel provision. Measure actual DC extension polarity, mating dimensions and grip. Freeze the approved input diagram and source selection before energising it.
*Revision labels: R17; change IDs: T17-4.*

Record USB input, board rails and barrel input voltages/current under the agreed load. Record the intended supply arrangement and unwanted coupling tests appropriate to it. Define numerical pass limits from matching component specifications first.
*Revision labels: R17; change IDs: T17-4.*

A17-08: with pump disconnected, identify coil/input/contact ratings and measure contact state through board reset, open logic input and both source power-up orders. Expected contact state is OFF throughout inhibit conditions; stop on any transient closure.
*Revision labels: R17; change IDs: T17-4.*

Verify an accessible physical pump-power disconnect, selected fuse/wire/contact ratings and motor suppression. Do not substitute a software OFF message for measured contact state.
*Revision labels: R17; change IDs: T17-4.*

| Action ID | Actual result / evidence | Verdict / operator / date |
| --- | --- | --- |
| A17-07 | ________________________ | Not tested / __________ |
| A17-08 | ________________________ | Not tested / __________ |

Owner: Unassigned. Target date: Not set. Deviations and corrective action: ____________________. Retest configuration/evidence: ____________________.

## 04 LCD, controls and dose measurements

| Action ID | Test | Expected acceptance | Existing status |
| --- | --- | --- | --- |
| A17-09 | LCD and controls | Display stable, buttons/lamps verified, dose return and full 60 s timeout observed | Partial serial record only |
| A17-10 | Dose and volume | Actual contact/pump durations and volume measured at selected endpoints | Not measured |

A17-09: with pump supply OFF, verify each switch and lamp; stable LCD status 0 and visible pages; STOP/release lockout; 1-4 s indicated endpoints; safe soil-index/fault test inputs; no automatic request from moisture.
*Revision labels: R17; change IDs: T17-4.*

Observe and record the actual LCD backlight after 60 s idle, button/knob wake and 60 s after completed/cancelled requests. Confirm immediate soil Status return at request end. Retain video/timed observation and serial as separate evidence.
*Revision labels: R17; change IDs: T17-4.*

A17-10: after power/reset protections pass, run a supervised measured pump trial using the approved supply and installed tube/lift. Measure contact ON duration and delivered volume at 1.0/4.0 s settings and intermediate points required by the intended use.
*Revision labels: R17; change IDs: T17-4.*

Timing and volume acceptance tolerances: Not yet defined. Record instrumentation resolution, repetitions, individual readings, mean/range and failures. Do not mark a test Pass without the pre-set numerical criteria.
*Revision labels: R17; change IDs: T17-4.*

| Action ID | Actual result / evidence | Verdict / operator / date |
| --- | --- | --- |
| A17-09 | ________________________ | Not tested / __________ |
| A17-10 | ________________________ | Not tested / __________ |

Owner: Unassigned. Target date: Not set. Deviations and corrective action: ____________________. Retest configuration/evidence: ____________________.

## 05 Leak/fill, print configuration and CAD exception

| Action ID | Test | Expected acceptance | Existing status |
| --- | --- | --- | --- |
| A17-11 | Leak/fill and wet route | Leak, drain-back, tilt/splash evidence; fill limit below unsealed openings recorded | Not tested |
| A17-12 | Material/print configuration | Material, slicer layers, orientation, local fit/strength recorded | Unknown |
| A17-13 | CAD shutdown anomaly | Clean CAD process log or isolated dependency defect with retained evidence | Open; build exits 1 |

A17-11: define leak-test duration, fill candidate, containment and acceptance first. Record actual water level, drain-back headspace, soil/drain condition, planter movement, tilt/splash exposure and dry-tower inspection. Fill mark acceptance needs physical evidence.
*Revision labels: R17; change IDs: T17-4.*

A17-12: record material and printing process, orientation/supports, layer inspection and measured critical holes. Representative screw and connector coupons must match the material/process of the intended body.
*Revision labels: R17; change IDs: T17-4.*

A17-13: retain the build output and exit code. Current R17 builder prints PASS but exits 1 during shutdown; independent STL checker exits 0. Closing this exception needs a clean process or isolated dependency-defect evidence; it never closes physical fit.
*Revision labels: R17; change IDs: T17-4.*

| Action ID | Actual result / evidence | Verdict / operator / date |
| --- | --- | --- |
| A17-11 | ________________________ | Not tested / __________ |
| A17-12 | ________________________ | Not tested / __________ |
| A17-13 | ________________________ | Not tested / __________ |

Owner: Unassigned. Target date: Not set. Deviations and corrective action: ____________________. Retest configuration/evidence: ____________________.

## 06 Close-out and disposition

| Action | Result | Evidence / owner / target |
| --- | --- | --- |
| A17-01 | Not tested / Open | ________________ |
| A17-02 | Not tested / Open | ________________ |
| A17-03 | Not tested / Open | ________________ |
| A17-04 | Not tested / Open | ________________ |
| A17-05 | Not tested / Open | ________________ |
| A17-06 | Not tested / Open | ________________ |
| A17-07 | Not tested / Open | ________________ |
| A17-08 | Not tested / Open | ________________ |
| A17-09 | Not tested / Open | ________________ |
| A17-10 | Not tested / Open | ________________ |
| A17-11 | Not tested / Open | ________________ |
| A17-12 | Not tested / Open | ________________ |
| A17-13 | Not tested / Open | ________________ |

Closed actions: None pre-populated. Open defects/deviations: ____________________. Reviewer/name/date: ____________________. Accepted configuration and limits: ____________________.
*Revision labels: R17; change IDs: T17-4.*

**CAUTION:** Current disposition remains prototype review with physical acceptance open. A signed worksheet closes only the identified test article and recorded criteria; it does not infer an ingress rating, certification or unattended-operation acceptance.

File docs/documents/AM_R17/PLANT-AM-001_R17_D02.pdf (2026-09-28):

## Plant Station R17 - Assembly Manual

Controlled field | Value
Document number | PLANT-AM-001
Plant design revision | R17
Document issue | D02
Issue date | 28 September 2026
Preceding document | PLANT-AM-001 R14 D01; original PLANT-AM-R14-UNO
Status | Issued for prototype review; physical acceptance open

Current mechanical configuration: R17 integrated body, R16 lid (R15 geometry), R13 fascia and planter. Electrical reference: frozen Uno UI v6 source and 27 September interface record. Fit, powered wet operation and unattended operation remain unaccepted.
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

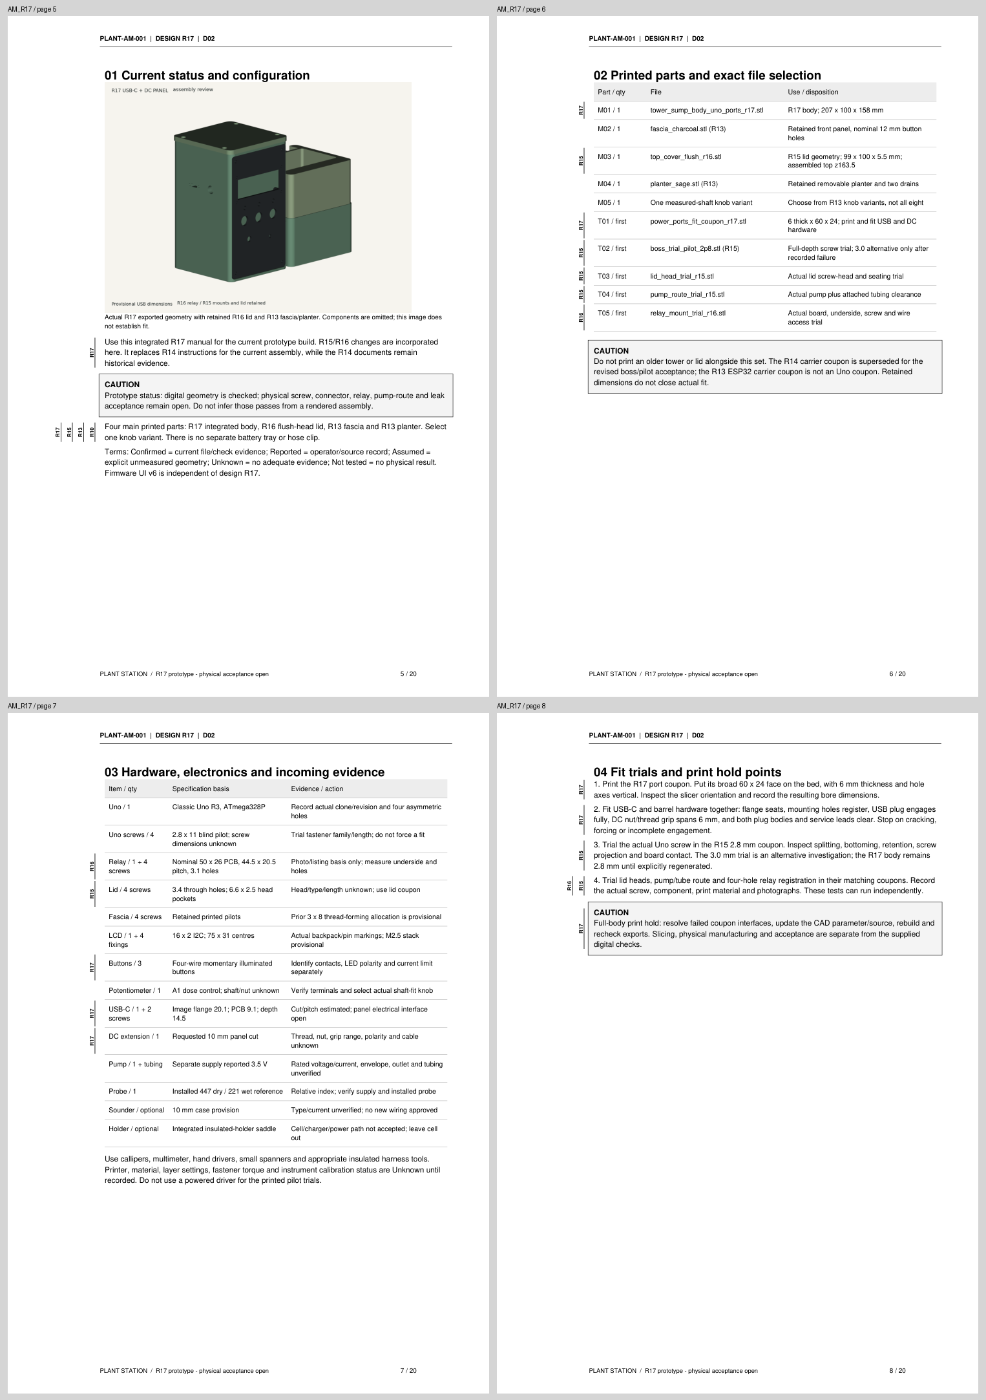
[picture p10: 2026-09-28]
docs/documents/AM_R17/rendered/contact-02.png

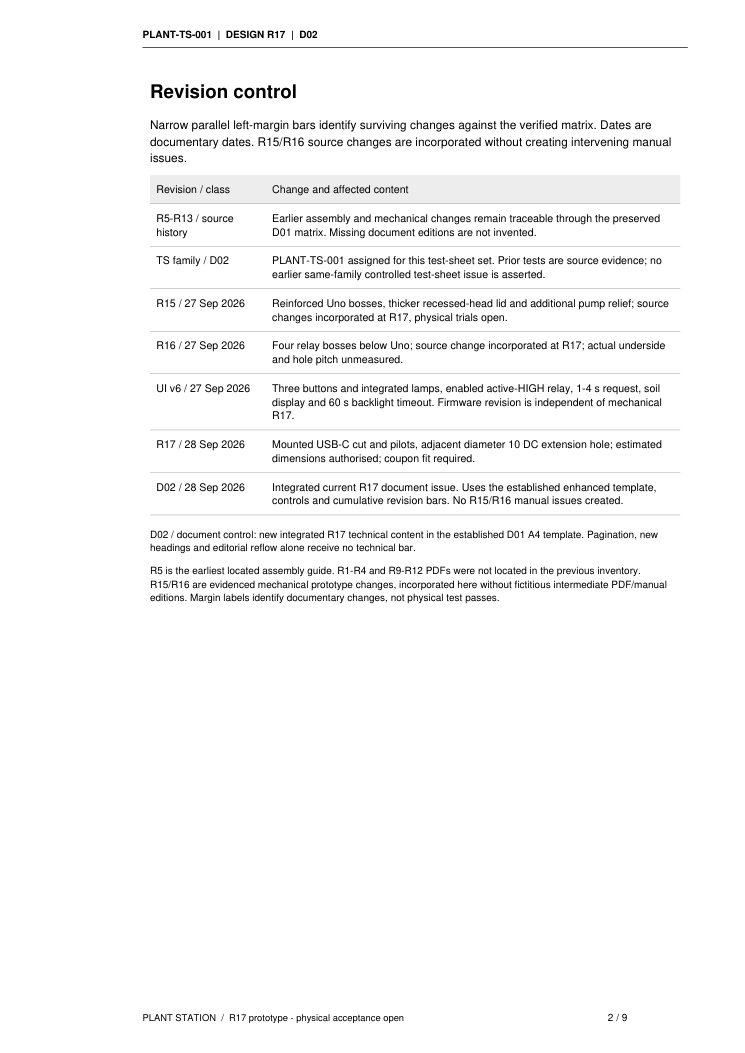
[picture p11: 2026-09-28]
docs/documents/TS_R17/rendered/page-002.png

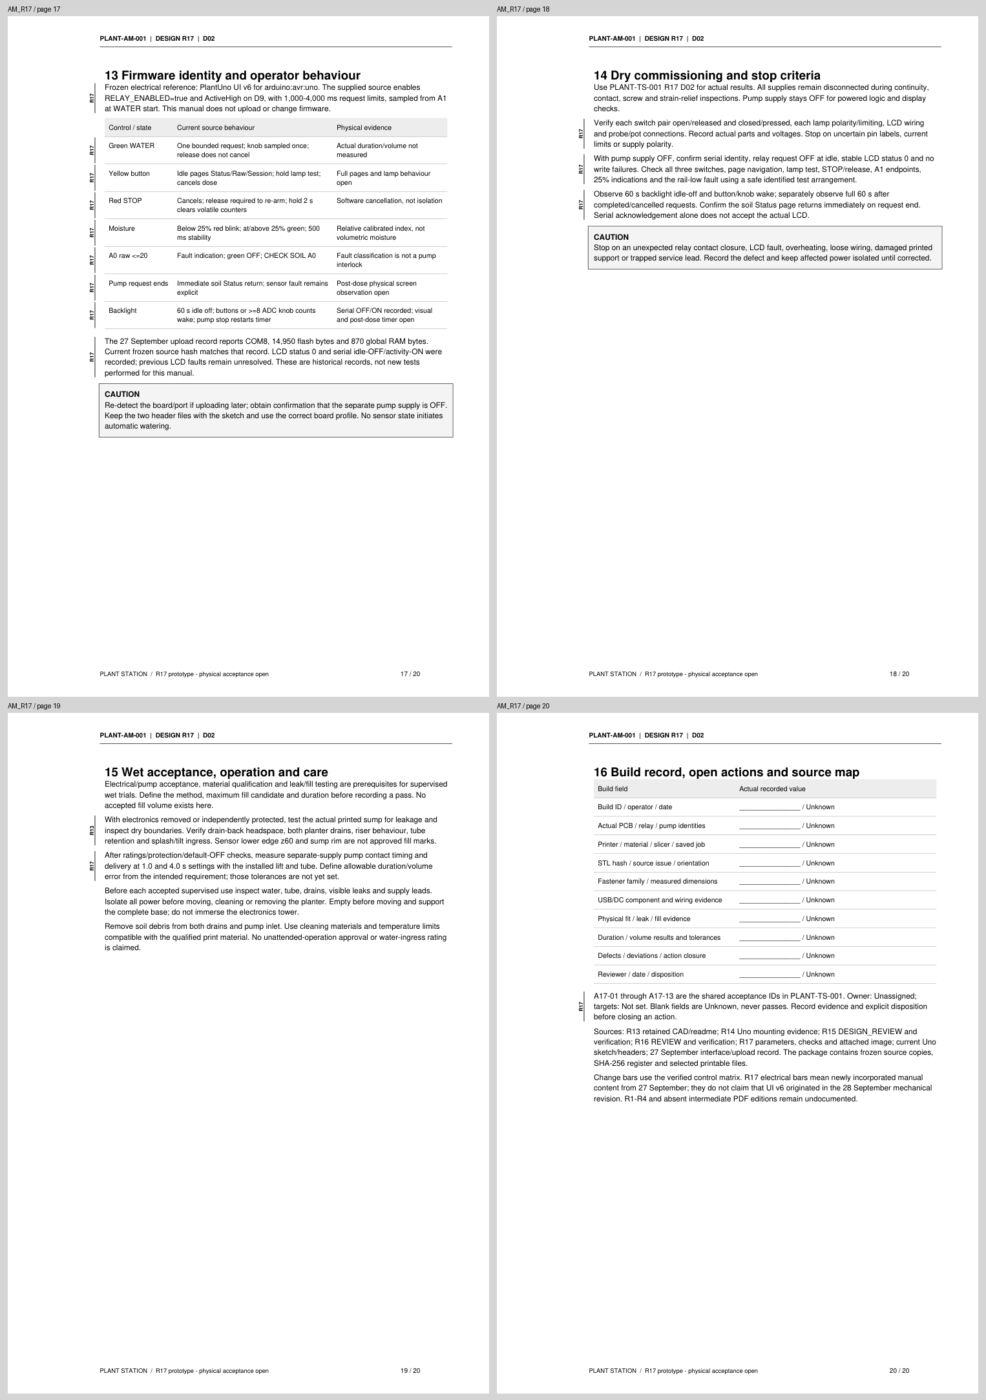
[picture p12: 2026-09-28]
docs/documents/AM_R17/rendered/contact-05.png

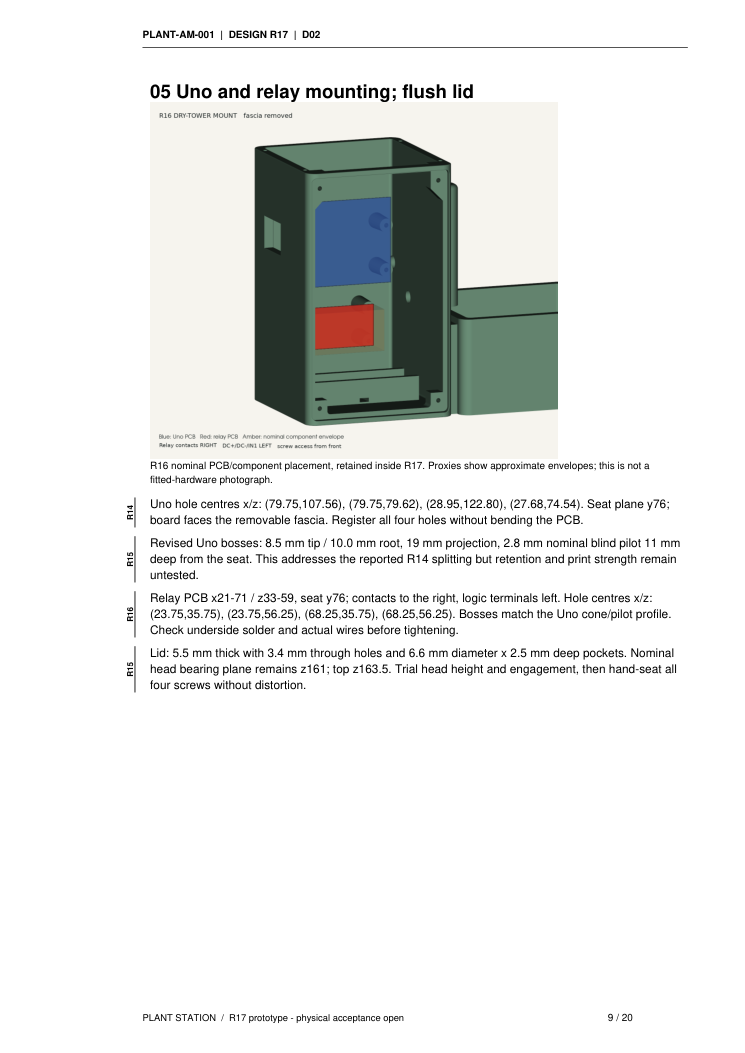
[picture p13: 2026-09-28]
docs/documents/AM_R17/rendered/page-009.png

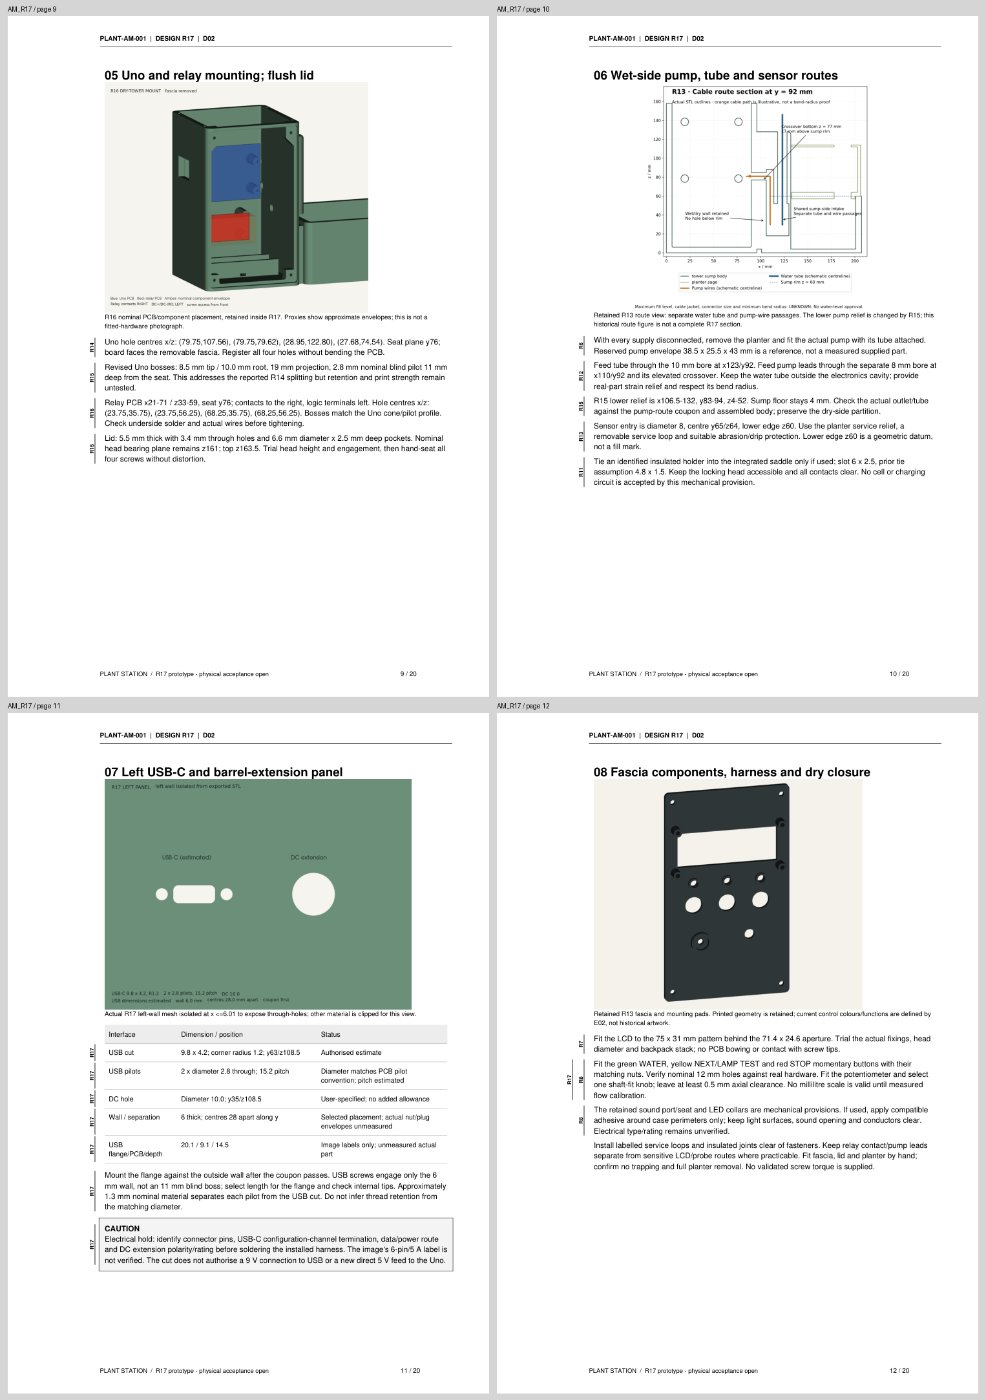
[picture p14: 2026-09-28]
docs/documents/AM_R17/rendered/contact-03.png

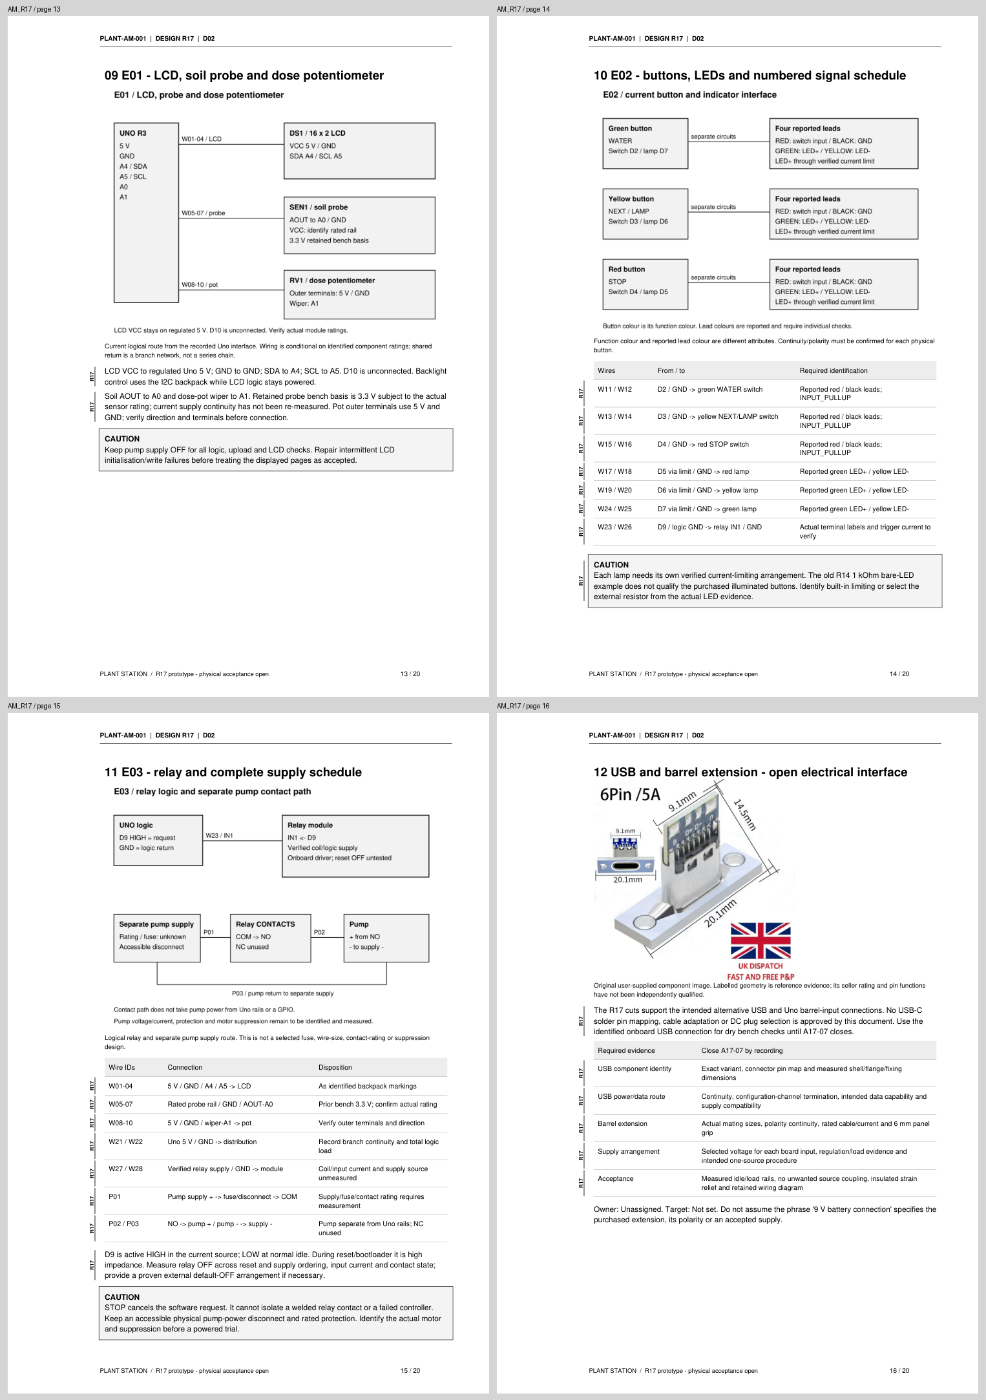
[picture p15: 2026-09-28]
docs/documents/AM_R17/rendered/contact-04.png

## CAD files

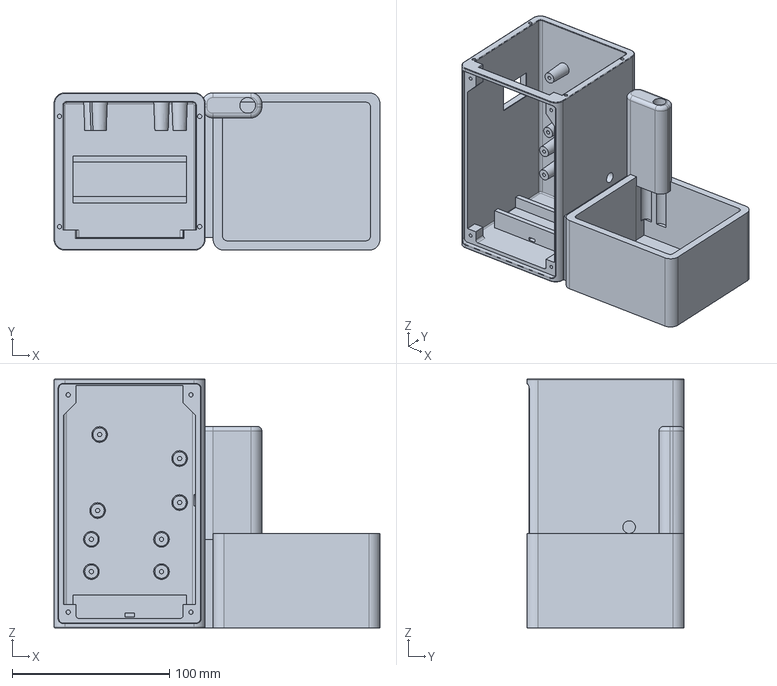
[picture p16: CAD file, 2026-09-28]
technical/cad/inputs/body_before_ports.step
207.0 x 100.0 x 158.0 mm

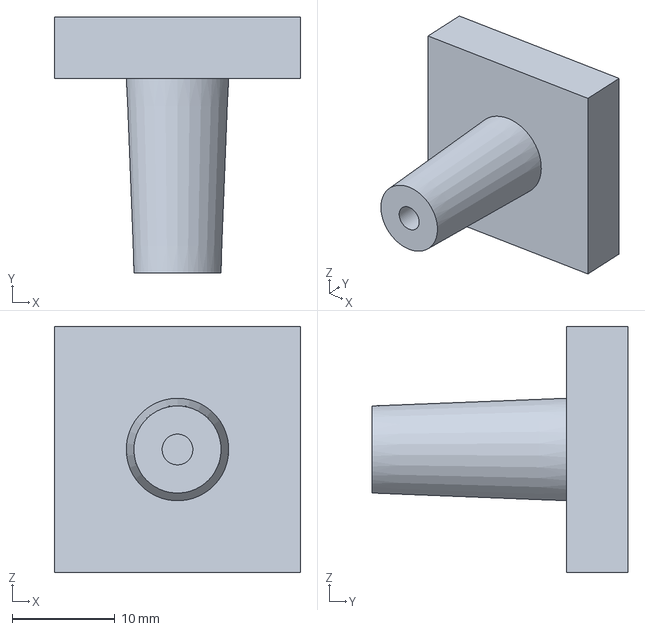
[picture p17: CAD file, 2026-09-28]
technical/print/fit_trials/step/boss_trial_pilot_3p0.step
24.0 x 25.0 x 24.0 mm

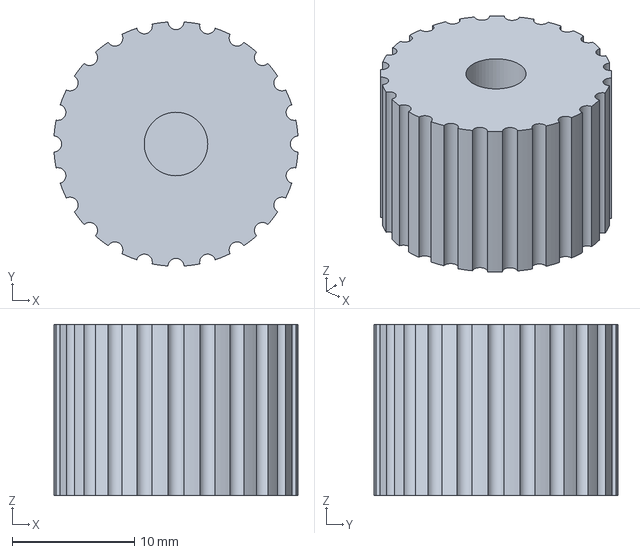
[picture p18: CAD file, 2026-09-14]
technical/print/knob_options/step/knob_round_5p2.step
20.0 x 20.0 x 14.0 mm

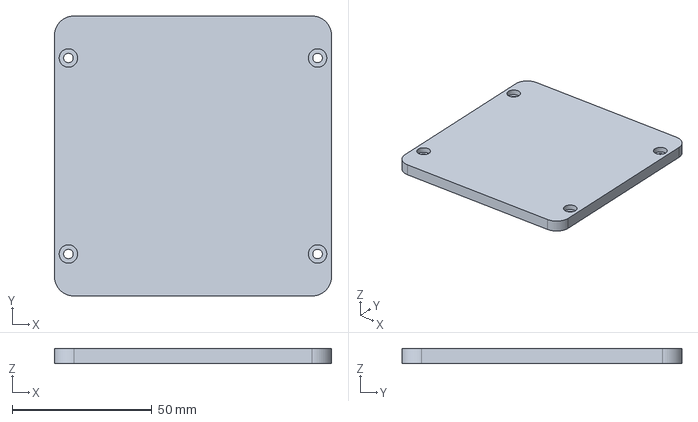
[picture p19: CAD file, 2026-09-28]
technical/print/main_parts/step/top_cover_flush_r16.step
99.0 x 100.0 x 5.50 mm

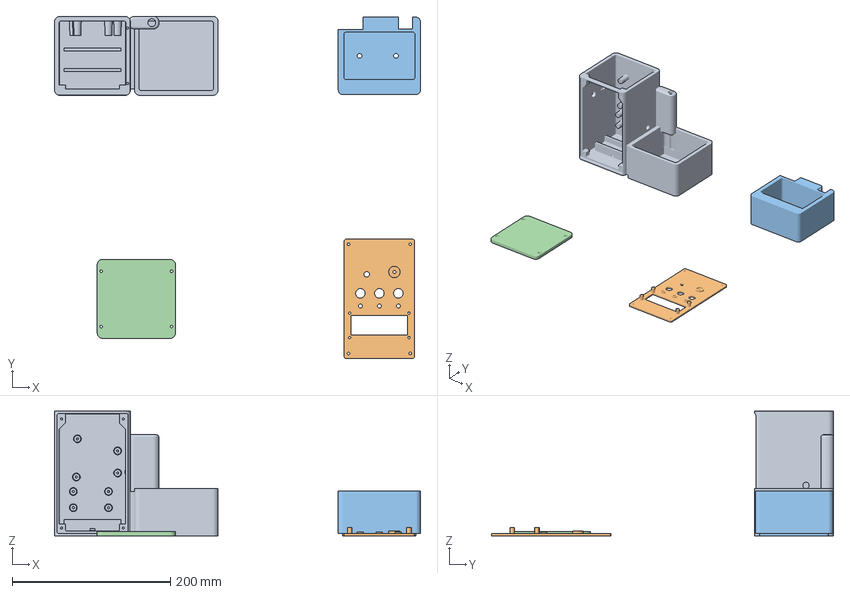
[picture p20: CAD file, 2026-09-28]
technical/print/plate_layout/r17_plate_layout.3mf
462.7 x 432.8 x 158.0 mm
tower_sump_body_uno_ports_r17.stl
fascia_charcoal.stl
planter_sage.stl
top_cover_flush_r15.stl

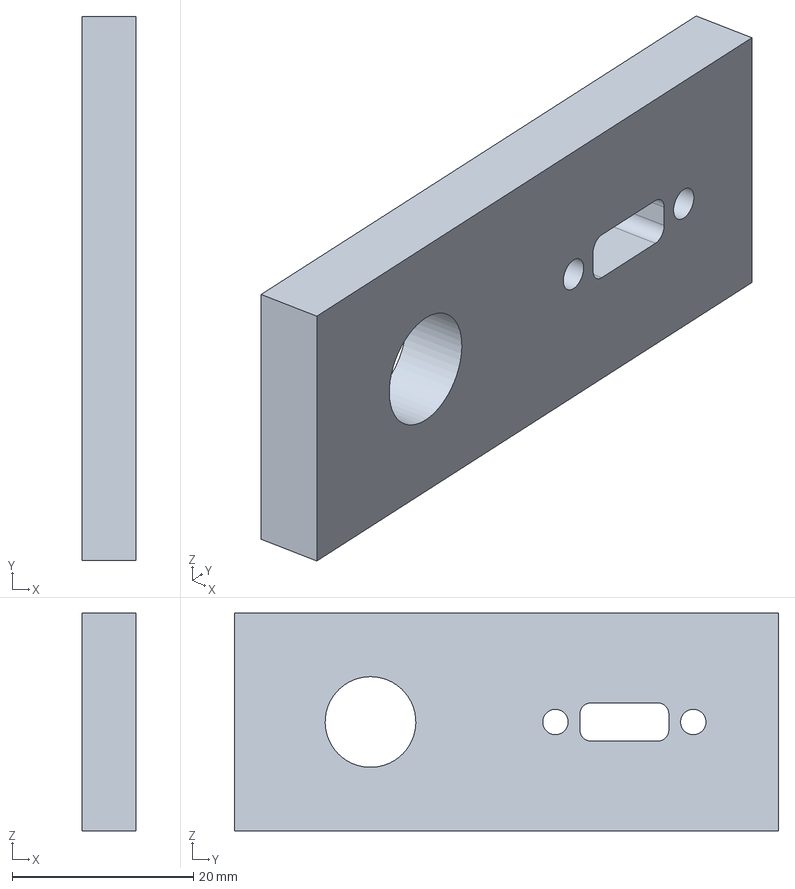
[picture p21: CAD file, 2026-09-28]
technical/print/fit_trials/step/power_ports_fit_coupon_r17.step
6.00 x 60.0 x 24.0 mm

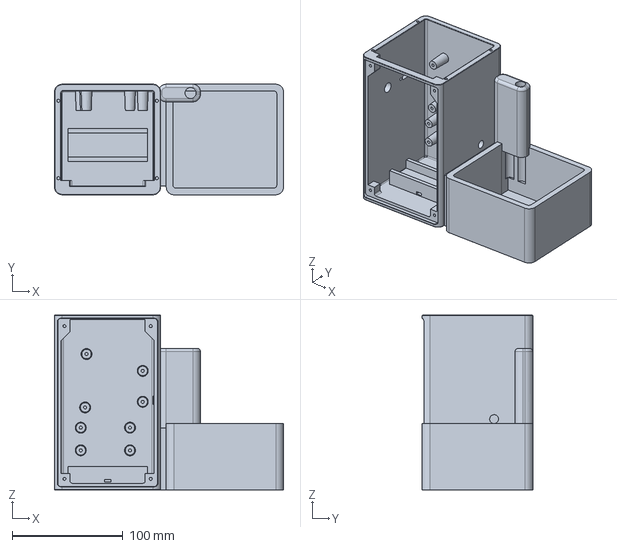
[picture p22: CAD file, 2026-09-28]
technical/print/main_parts/step/tower_sump_body_uno_ports_r17.step
207.0 x 100.0 x 158.0 mm

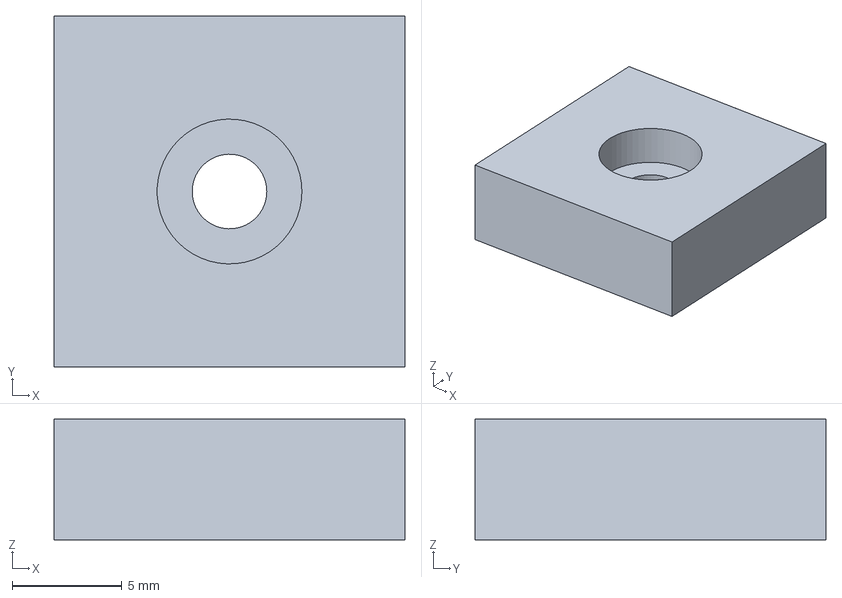
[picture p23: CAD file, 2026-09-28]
technical/print/fit_trials/step/lid_head_trial_r15.step
16.0 x 16.0 x 5.50 mm

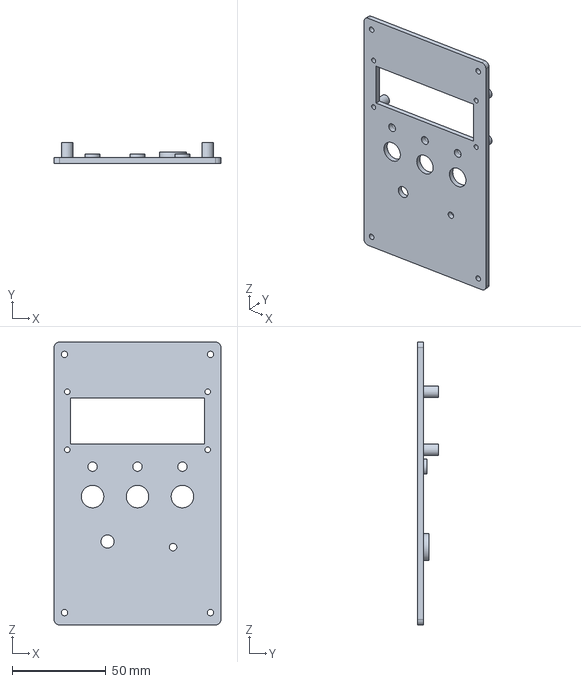
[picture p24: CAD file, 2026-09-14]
technical/print/main_parts/step/fascia_charcoal.step
89.2 x 11.0 x 151.2 mm

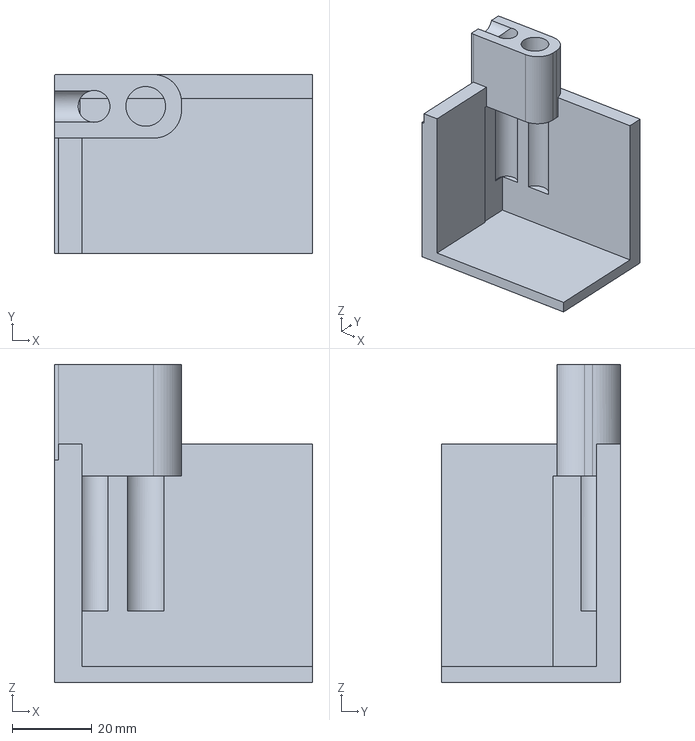
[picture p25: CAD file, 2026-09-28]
technical/print/fit_trials/step/pump_route_trial_r15.step
65.0 x 45.0 x 80.0 mm

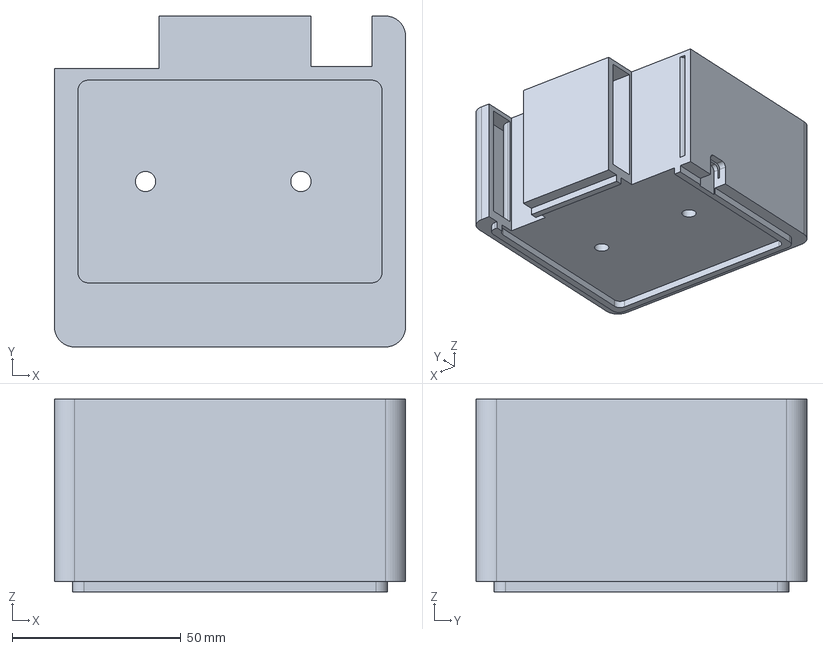
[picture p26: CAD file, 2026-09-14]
technical/print/main_parts/step/planter_sage.step
104.0 x 98.0 x 57.0 mm

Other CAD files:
technical/print/slicer_exports/planter_r17.gcode.3mf
technical/print/knob_options/step/knob_round_6p2.step
technical/print/slicer_exports/tower_r17.gcode.3mf
technical/print/knob_options/step/knob_round_6p55.step
technical/print/slicer_exports/lid_r17.gcode.3mf
technical/print/knob_options/step/knob_round_6p0.step
technical/print/slicer_exports/fascia_r17.gcode.3mf
technical/print/fit_trials/step/boss_trial_pilot_2p8.step
technical/print/fit_trials/step/button_fit_coupon.step
technical/print/fit_trials/step/knob_fit_coupon.step
technical/print/fit_trials/step/lcd_fit_coupon.step
technical/print/fit_trials/step/piezo_led_fit_coupon.step
technical/print/fit_trials/step/relay_mount_trial_r16.step
technical/print/fit_trials/step/upper_boss_print_coupon.step
technical/print/fit_trials/stl/boss_trial_pilot_2p8.stl
technical/print/fit_trials/stl/boss_trial_pilot_3p0.stl
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

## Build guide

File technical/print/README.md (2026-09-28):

# Current print exports

`manifest.json` lists all 46 selected STL/STEP files, SHA-256 hashes and original source revisions. Units: mm. STL contains no explicit units metadata.

- `main_parts/`: R17 integrated body, R16 lid with R15 geometry, R13 fascia and R13 planter.
- `fit_trials/`: 11 representative port, screw/boss, relay, lid, pump-route and control-fit trials. Print relevant trials before the full body.
- `knob_options/`: eight bore choices; select one using the actual shaft and fit trial.
- `plate_layout/`: user-supplied Bambu Studio four-plate project for the main models. Its published hash and component geometry comparison are in `../../verification/plate_layout.json`; settings are not manufacturing approval.
- `slicer_exports/`: four operator-supplied sliced printer files; executable commands unchanged, publication metadata and checksums controlled in `../../verification/slicer_exports.json`. Physical operation remains untested.

Trial outcomes remain open. The port coupon has the same estimated USB aperture/pilots and user-requested Ø10 mm DC opening as the current tower. See the assembly manual and test sheets for selection, print orientation and acceptance criteria.

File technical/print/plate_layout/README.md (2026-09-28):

# User plate layout — R17

`r17_plate_layout.3mf` is a publication copy of the four-plate Bambu Studio project added by the user during the repository cleanup. It targets the stored X1 Carbon profile. All four model meshes match the canonical main-part STLs within 0.0002 mm in the source frame; the retained R15-labelled lid model matches the current R16 export of that geometry.

Geometry members, plate transforms, thumbnails and nonfinancial settings are preserved. The publication copy removes the account identifier from model metadata and filament-price fields from the project settings. The unmodified original is retained in the external local archive; original and publication hashes and the changed-member list are recorded in `verification/plate_layout.json`.

No G-code member is present. Existing thumbnail/layer metadata does not establish successful current slicing, printing or acceptance. Inspect settings and layers against the actual printer, nozzle and filament. Complete the fit trials before printing the full body. No knob or coupons are included in this four-main-part project.

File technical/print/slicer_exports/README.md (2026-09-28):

# Operator slicer exports — R17

Four Bambu Studio X1 Carbon files were added by the user during publication:

| Published file | Original filename | Stored plate |
|---|---|---|
| `tower_r17.gcode.3mf` | Tower R17.gcode.3mf | 1 |
| `planter_r17.gcode.3mf` | Planter R17.gcode.3mf | 2 |
| `lid_r17.gcode.3mf` | Lid R17.gcode.3mf | 3 |
| `fascia_r17.gcode.3mf` | front panel R17.gcode.3mf | 4 |

These are operator-supplied machine exports, distinct from the editable four-plate project and canonical STL/STEP geometry. The exported containers do not retain the model meshes required for an independent toolpath-to-CAD comparison. Their filenames/plate metadata establish the supplied identification; actual print quality and relationship of all settings to the intended manufacture remain unverified.

Publication copies remove the account identifier, filament-price fields and one price-only G-code comment. Every other G-code byte is preserved; no executable command is changed. The embedded G-code MD5 is recalculated and verified. All unchanged archive members are byte-identical to the received originals. Original and publication SHA-256 hashes, changed-member lists and checksum results are recorded in `verification/slicer_exports.json`. Unmodified originals remain in the external local backup.

No file has been sent to a printer or executed by this publication. Inspect the chosen printer, nozzle, filament, settings and layers before use; complete the relevant fit trials and acceptance sheets. Stored duration, material and layer estimates are slicer output, not observed printing results.

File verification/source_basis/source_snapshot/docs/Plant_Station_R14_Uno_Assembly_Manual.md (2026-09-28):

# R14 UNO | Assembly manual

PLANT STATION / PLANT-AM-R14-UNO / Issue A / 20 September 2026

R14 tower and Uno mounting geometry. Actual CAD view; electronics omitted.

Mechanical assembly, wiring and commissioning

A workshop manual for junior engineers assembling one Arduino Uno R3 plant station. Includes the complete mechanical sequence, component schedule, numbered harness drawings and test records.

<b>Build status:</b> mechanical prototype and motor-disabled bench electronics. This finished manual does not certify a finished watering appliance. Actual fit, pump power/driver selection and wet acceptance remain open.

Geometry: R14 tower with retained R13 fascia, roof and planter. Mechanical documentation baseline: R14-D2. Electrical reference: saved PlantUno bench v2 source.

<b>Files and updates:</b> <link href="https://github.com/skyhigh6/esp32-plant-station" color="#167d8d">https://github.com/skyhigh6/esp32-plant-station</link>

# 01 | Read first and obtain the files

Pages | Use
--- | ---
3-4 | BOM and incoming inspection
5-9 | Incoming inspection, fit trials and mechanical assembly
10-14 | Uno orientation, wiring diagrams and wire schedule
15 | Future pump circuit - design hold
16-17 | Firmware and dry commissioning
18-19 | Wet acceptance, care and build record
20 | Evidence, sources and revision control

Download the controlled configuration

Open the repository above, choose <b>Code &gt; Download ZIP</b>, extract it, and record the commit from the repository history. Do not print every STL in the repository; older revisions remain for traceability.

<link href="https://github.com/skyhigh6/esp32-plant-station/blob/18ab0d889db349c712b43624d315e4f15ed3ebe2/mechanical/concept_rev14_uno/README.md" color="#167d8d">R14 tower, coupon and STEP files</link><br/><link href="https://github.com/skyhigh6/esp32-plant-station/blob/18ab0d889db349c712b43624d315e4f15ed3ebe2/mechanical/concept_rev13/README.md" color="#167d8d">Retained R13 parts</link><br/><link href="https://github.com/skyhigh6/esp32-plant-station/blob/18ab0d889db349c712b43624d315e4f15ed3ebe2/Plant_Station_R14_Uno_Review.zip" color="#167d8d">Complete mechanical review archive</link><br/><link href="https://github.com/skyhigh6/esp32-plant-station/blob/18ab0d889db349c712b43624d315e4f15ed3ebe2/output/pdf/Plant_Station_R14_Uno_Assembly_Manual.pdf" color="#167d8d">This assembly manual</link><br/><link href="https://github.com/skyhigh6/esp32-plant-station/blob/18ab0d889db349c712b43624d315e4f15ed3ebe2/docs/r14_uno_reference/PlantUno/PlantUno.ino" color="#167d8d">Bench firmware snapshot used by this manual</link>

<b>Excluded:</b> the purchased panel USB-C breakout is not fitted or wired. Adding it later requires a separate enclosure/print and electrical revision. The Uno's existing onboard USB socket remains the bench programming/power connection.

<b>Terms:</b> confirmed = supported by inspected files or test evidence; reported = user record; proposed = selected here but not physically qualified; unknown = inspect or measure before use. A drawing connection applies only after the component matches its stated type.

# 02 | BOM - printed parts and fasteners

ID / qty | Part / source | Specification and disposition
--- | --- | ---
M01 / 1 | R14 tower_sump_body_uno.stl | Integrated tower, sump and holder saddle; 207 x 100 x 158 mm.
M02 / 1 | R13 fascia_charcoal.stl | LCD, three nominal 12 mm buttons, 7 mm pot bore.
M03 / 1 | R13 top_cover_sage.stl | Retained roof; assembled height approximately 161 mm.
M04 / 1 | R13 planter_sage.stl | Retained planter, two drains and service reliefs.
M05 / 1 | R13 selected knob STL | Choose round or D shaft after measurement; print one variant.
T01 / 1 | R14 uno_mount_fit_coupon.stl | Mandatory board registration and pilot trial.
T02 / as needed | R13 fit coupons | LCD, button, knob, piezo/LED and upper boss coupons. Do not use carrier coupon for Uno.
F01 / 4 | Uno screws | M3 candidate; length/head/thread process selected by trial. Pilot 2.8 mm x 11 mm deep.
F02 / 8 | Fascia + roof screws | 4 each; 3 x 8 mm plastic thread-forming is provisional. Verify actual engagement.
F03 / 4 sets | LCD screws and nuts | M2.5 x 16 mm provisional; head <=5.5 mm. Verify stack and thread projection.
F04 / 4 sets | Component nuts/washers | Three buttons and one potentiometer; supplied matching hardware.
F05 / 1 | Holder cable tie, optional | 4.8 x 1.5 mm provisional; tunnel 6 x 2.5 mm. No cell fitted.

<b>Purchased hardware evidence:</b> Photo 2 shows an M2/M2.5/M3 button-head screw, Nyloc nut and washer listing, plus a 2.2-6.0 mm plastic self-tapping screw listing. The selected sizes, lengths and quantities are not visible. Sort and measure the delivered parts; listing ranges are not fit specifications.

Machine screws and plastic thread-forming screws are different systems. Do not force an M3 machine screw into an unqualified printed pilot. A Nyloc nut is not used behind a blind tower boss. No separate battery-tray or hose-clip screws are required.

# 03 | BOM - electronics and consumables

ID / qty | Component | Build requirement / evidence
--- | --- | ---
U1 / 1 | Arduino Uno R3 | Classic 5 V ATmega328P; actual clone/board markings to record. Not Uno R4.
DS1 / 1 | 16 x 2 I2C LCD | Existing QAPASS/PCF8574 assumed; verify labels and 5 V rating. Saved v2 LCD test passed.
SEN1 / 1 | Capacitive soil probe | Existing v1.2 reported; verify 3.3 V operation and pin order.
RV1 / 1 | Linear potentiometer | 10 kOhm proposed if purchasing; verify actual resistance, shaft and terminals.
SW1-3 / 3 | Illuminated panel switches | Photos show red, green and yellow ring listings. Diameter, momentary/latching option and ring voltage unknown.
LED1-3 / 3 | Low-current indicator LEDs | Reference circuit: red lockout, blue dose, green ready. Separate LEDs unless ring ratings are verified.
R1-3 / 3 | 1 kOhm resistors | One per bare LED; 0.25 W adequate for this circuit.
PS1 / 1 | Uno USB data/power lead | Match actual onboard socket. Dry bench supply only; no external 5 V injection.
P1 / 1 | DC pump | 3.3 V reported; actual label, current, outlet and envelope to verify. Leave disconnected.
DRV1 / 1 set | Pump driver and supply | Not selected; MOSFET, diode, gate resistors, fused regulated supply and disconnect required. See p15.
BZ1 / 1 | 10 mm case sounder | Type/current/height unconfirmed; no connection in this issue.
BAT1 / optional | 18650 holder/power system | Mechanical provision only. Cell, charger/protection and power path not released.
C01 / as needed | Harness and wet-side items | Insulated wire, labels, connectors, heatshrink, edge protection, strain relief, measured tubing, drain screens; compatible sealing material if needed.

Use approximately 0.2-0.35 mm2 flexible insulated wire for short low-current bench signal runs. Motor wire, supply rating and fuse depend on measured current. Label both ends of every wire; colours alone are insufficient.

Bought does not mean electrically identified. Do not connect the unknown illuminated rings, sounder, cell or motor to an Uno pin. The USB-C panel module is deliberately omitted from this BOM.

# 04 | Incoming inspection and tools

Tools and preparation

Use callipers, a multimeter with continuity and DC-voltage ranges, hand screwdrivers, small spanners, cutters, wire stripper, suitable crimp/solder tools and heatshrink. Keep the bench dry. Disconnect USB and all supplies before handling wiring. Use a current-limited supply for future motor characterisation.

Check | Method | Pass / action
--- | --- | ---
Switch action | Meter on unpowered contact pair; operate and release. | Normally open at rest; closed only while pressed. Latching switches do not meet the current interface.
Switch contacts vs ring | Use supplier terminal drawing and meter; identify COM/NO/NC and LED +/-. | Record labels. Use COM/NO only; insulate NC. Do not identify lamp wires by colour alone.
Ring rating | Read selected order details, markings or matching supplier data. | Record voltage, current, polarity and any internal resistor. Leave isolated until known.
Panel fit | Measure barrel, nut, rear projection and pot bushing. | Trial coupon and fascia without forcing; nominal button bore 12 mm.
Fasteners | Measure diameter/under-head length; identify thread family. | Trial on coupon. Record engagement and positive bottoming clearance.
LCD and probe | Read module labels, supply ratings and connector order. | Follow labels, not the apparent order in a generic diagram.
Board and cables | Record board revision; inspect underside and plug envelope. | All four Uno holes register; USB insertion and service access verified.

Hold point HP1: do not print the complete tower until the Uno coupon and screw-fit trials pass. Do not energise any unidentified module. Record failures rather than modifying parts until they appear to fit.

# 05 | Fit and mount the Arduino Uno

R14 exported-mesh mount sections. Nominal dimensions; print fit remains to be checked.

<b>1.</b> Print the Uno coupon at 100% scale in the intended process. Offer it to the PCB underside with its screw-test boss facing away. All four 3.2 mm gauge holes must register without board bending.

<b>2.</b> Trial screw/thread preparation in the 2.8 mm coupon pilot. Its boss is 8 mm high: use a short trial screw. It does not reproduce the tower's 11 mm blind depth.

<b>3.</b> Inspect the full tower print: roots sound, support removed, pilots clear, seating faces coplanar and wet/dry divider undamaged. Record printer, material, scale, orientation, layer height and supports.

<b>4.</b> Insert the Uno through the front with fascia and roof removed. Components face the fascia; USB faces left. PCB underside seats at y76; rear wall y94 gives 18 mm nominal rear clearance.

<b>5.</b> Fit four qualified screws. Engagement = under-head length minus measured PCB/washer stack. Keep engagement below 11 mm with positive bottoming margin. Hand-tighten; no torque is qualified. Check all supports contact without bowing.

HP2: check screw heads, solder joints, headers, USB/power plugs and cable removal with the fascia in place. The retained side aperture was designed for the earlier carrier; direct Uno USB access is not established by the mount geometry.

# 06 | Assemble the wet-side routes

Retained R13 service-riser geometry; unchanged by the R14 mount revision.

<b>6.</b> Inspect sump floor and walls for cracks/pinholes. Remove print debris and clear both planter drains. Trial the pump, leaving it electrically disconnected. The CAD reference envelope is 38.5 x 25.5 x 43 mm; it is not the measured 3.3 V pump.

<b>7.</b> Feed the water tube through the 10 mm bore at x123/y92. Keep the tube outside the electronics cavity. Actual tube OD, connector size, bend radius and outlet retention must be checked; the old separate hose clip is not used.

<b>8.</b> Route the two isolated pump leads through the separate 8 mm bore at x110/y92 and the crossover into the tower. Keep leads free from abrasion and moving/removed parts. Insulate both ends pending driver selection.

<b>9.</b> Trial the planter through its full insertion/removal travel. Fit removable debris guards without blocking the two drains. Provide enough slack to service the pump and planter without pulling connections.

No water during electrical assembly. The sump rim at z60 is not a fill mark. Printed passages are not sealed glands; no maximum fill volume has been qualified.

# 07 | Sensor route and fascia components

Retained sensor entry: diameter 8 mm, centre y65/z64; lower edge z60.

<b>10.</b> Route the probe lead through the sensor entry and matching planter relief. Add suitable edge protection and strain relief. Leave a service loop; keep the probe electronics above the wetting/soil limit for the actual sensor.

<b>11.</b> Mount the LCD on the fascia rear: reference centres 75 x 31 mm, aperture 71.4 x 24.6 mm. Trial four M2.5 screws/nuts; avoid board bow and conductor contact. Verify backpack depth and access to the contrast trimmer.

<b>12.</b> Fit the identified momentary buttons and potentiometer using supplied nuts/washers. Match actual parts to the 12 mm and 7 mm nominal bores. Fit the selected knob with at least 0.5 mm axial clearance.

<b>13.</b> For the existing firmware, label WATER and LAMP TEST. The third switch is SPARE / NOT ACTIVE; do not label it STOP while USE_STOP=false. Switch colour does not establish its function.

<b>14.</b> Fit separate reference LEDs or retain ring wires insulated pending identification. Red=lockout, blue=dose request and green=ready are the software meanings. Yellow purchased ring is not an automatic electrical substitute for blue.

Keep the unidentified sounder disconnected. If fitting an empty insulated holder, route a tie through the 6 x 2.5 mm saddle tunnel before installing it; leave the cell out. Battery operation is outside this issue.

# 08 | Harness installation and closure

Retained fascia CAD. Component bodies and harness must be checked on the actual build.

<b>15.</b> Build the harness on the bench using pages 10-14. Number both ends W01 onward and label components U1, DS1, SEN1, RV1 and SW1/SW2. Use insulated distribution terminals for shared 5 V, 3.3 V and ground; do not stuff multiple bare ends into an Uno socket.

<b>16.</b> Verify each wire against the schedule with power off. Confirm no crossed supply rails, no uninsulated joints, correct LED polarity/resistors and correct COM/NO switch contacts. Tug-test terminations gently.

<b>17.</b> Complete dry bench commissioning with the assembly open. Then disconnect power, arrange service loops and retain the harness away from screw tips, wet openings and sharp edges.

<b>18.</b> Offer up the fascia and fit four qualified screws. Refit the roof with four screws. Hand-tighten only. Ensure cables cannot be pinched between mating faces.

<b>19.</b> Fit and remove the planter again. Check both drains, tube bend, sensor lead, pump leads, USB access and cover seating. Photograph the internal routing before final closure.

HP3: all dry mechanical and electrical checks must pass before closing the assembly. Power remains USB bench power; no motor, external supply, battery or panel USB-C connection is included.

# 09 | Uno R3 orientation and terminal map

See vector wiring drawing in PDF: board

Simplified top view with the onboard USB socket at the left. Header order is shown for orientation; spacing and board outline are schematic. Verify the printed pin labels on the actual Uno/clone before connecting.

Terminal | Connection
--- | ---
5V / GND | LCD and pot supply / common return
3.3V / A0 / A1 | Probe supply / probe output / pot wiper
A4 / A5 | LCD SDA / SCL; not digital D4 / D5
D2 / D3 | WATER / LAMP TEST normally-open contacts
D5 / D6 / D7 | Red / blue / green reference LED via individual 1 kOhm resistor
D4 / D8 / D9 | Unused STOP / sounder reserve / motor reserve; leave disconnected

The dedicated SDA/SCL header duplicates A4/A5; use one connection set. D0/D1 remain free for USB serial. Use the Uno's onboard USB connector for this bench configuration. See official pinout source S1 on p20.

# 10 | Wiring drawing E01 - LCD and analogue

See vector wiring drawing in PDF: analogue

Read the drawing

Each horizontal line is one physical wire. Wire ID is the primary identifier; colour is secondary. Separate GND wires join at a common insulated ground distribution point connected to Uno GND. Component terminal positions are functional, not a claim about connector order.

<b>LCD:</b> VCC=5 V, GND=ground, SDA=A4, SCL=A5. Check the backpack labels. Adjust contrast only after successful I2C initialisation. No ESP32 level shifter is used in this 5 V Uno/5 V backpack arrangement.

<b>Probe:</b> verify the actual module works at 3.3 V. VCC=3.3 V, GND=ground, AOUT=A0. Keep its output within the Uno input range and never connect an unknown 5 V output to the 3.3 V supply terminal.

<b>Pot:</b> outer terminals to 5 V/GND, wiper to A1. Identify the wiper with a meter. Swap only the two outer leads if clockwise decreases the setting. This prototype has no validated open-wiper fail-low circuit.

Orange is 3.3 V; red is 5 V. Never bridge these rails. The probe is the only proposed 3.3 V load; measure its current and check the actual board capacity before energising.

# 11 | Wiring drawing E02 - controls and LEDs

See vector wiring drawing in PDF: controls

<b>Switch detail:</b> W11 goes to SW1 COM and W12 returns SW1 NO to GND; W13/W14 do the same for SW2. COM and NO may be interchanged electrically. A four/five-terminal illuminated switch has a separate lamp circuit: do not bridge it to the contact pair.

<b>LED detail:</b> D5/D6/D7 each feeds its own 1 kOhm resistor, then the LED anode (+). Each cathode (-) returns to GND. The resistor may physically sit at either end of its series branch; never omit it for a bare LED.

At 5 V, 1 kOhm limits each bare-LED branch to less than 5 mA, even before LED forward voltage is considered. This is a low-current indication circuit; brightness is not yet qualified.

<b>Purchased rings:</b> keep isolated until their rated voltage/current and internal resistor are known. A 12 V ring is not powered from 5 V, and an unknown ring is not driven directly by GPIO. If the rings need a driver, issue a revised drawing. The red/green/yellow purchases do not establish the red/blue/green reference LED circuit.

SW3 and its lamp remain spare. LAMP TEST cancels the simulated dose; a three-press gesture also enters diagnostics. There is no active dedicated STOP button in the supplied bench snapshot.

# 12 | Wire schedule - power and analogue

Wire / colour | From | To | Check
--- | --- | --- | ---
W01 / red | U1 5V via +5V terminal | DS1 VCC | 5 V-rated LCD only
W02 / black | Ground terminal | DS1 GND | Common ground
W03 / blue | U1 A4 | DS1 SDA | Not D4
W04 / yellow | U1 A5 | DS1 SCL | Not D5
W05 / orange | U1 3.3V | SEN1 VCC | Module rating verified
W06 / black | Ground terminal | SEN1 GND | Verify module label
W07 / green | SEN1 AOUT | U1 A0 | Analogue output
W08 / red | +5V terminal | RV1 high outer | Check direction
W09 / black | Ground terminal | RV1 low outer | Check direction
W10 / violet | RV1 wiper | U1 A1 | Variable 0-5 V
W21 / red | U1 5V | +5V distribution terminal | Feeds W01 and W08
W22 / black | U1 GND | Ground distribution terminal | Feeds all return wires

Harness conventions

E01/E02 show logical nets. W21 and W22 are the physical feeder wires to the shared distribution terminals. Each branch has its own numbered conductor. Do not put a component in series with another component's ground return.

Fit a removable connector where servicing requires it, with matching labels on both halves. Record connector pin order in the build record; no connector family or cavity assignment is implied here. Keep sensor signal and I2C runs short and separated from future motor-current wiring.

Before USB connection, disconnect unknown modules and check for wiring shorts with the meter. Electronic circuits can show changing resistance while capacitors charge; investigate a persistent near-zero supply-to-ground reading. Do not use resistance/continuity mode on a powered circuit.

# 13 | Wire schedule - controls and indicators

Wire / colour | From | To | Function
--- | --- | --- | ---
W11 / white | U1 D2 | SW1 COM | WATER input
W12 / black | SW1 NO | Ground terminal | WATER return
W13 / grey | U1 D3 | SW2 COM | LAMP input
W14 / black | SW2 NO | Ground terminal | LAMP return
W15 / red | U1 D5 | R1 1 kOhm -> LED1 anode | Red lockout
W16 / black | LED1 cathode | Ground terminal | LED1 return
W17 / blue | U1 D6 | R2 1 kOhm -> LED2 anode | Blue dose request
W18 / black | LED2 cathode | Ground terminal | LED2 return
W19 / green | U1 D7 | R3 1 kOhm -> LED3 anode | Green ready
W20 / black | LED3 cathode | Ground terminal | LED3 return

Each W15/W17/W19 identifier covers its wired series branch to the resistor. Mount the resistor adjacent to the LED and sleeve the resistor-to-anode joint; label the branch ends. Each LED return remains separately numbered.

Reserved terminal | Issue A disposition
--- | ---
D4 | No wire; USE_STOP=false. SW3 is spare, not a safety stop.
D8 | No wire; unidentified sounder left disconnected.
D9 | No wire in the bench harness; MOTOR_ENABLED=false keeps output LOW.
VIN / barrel / external 5V | No external supply connection in this build.
Panel USB-C / cell | Excluded. No connection to any supply rail.

White/grey wire must still carry its W-number because colour discrimination is not an acceptance method. Supplier lead colours do not override the verified terminal identity. Keep spare leads individually insulated.

# 14 | Future pump driver - design hold

See vector wiring drawing in PDF: pump

E03 is a complete circuit concept, not an instruction to energise the present pump. The pump is reported as 3.3 V, but its actual identity, startup/stall current and duty limits are unknown. Select parts only after those measurements and matching datasheets are available.

Future ID | Connection / selection criterion
--- | ---
W30 brown | D9 -> 100-220 Ohm gate resistor -> Q1 gate.
W31 black | Uno GND -> motor supply GND / Q1 source; shared reference.
W32 red | Regulated 3.3 V supply + -> fuse/disconnect -> motor +.
W33 black | Motor - -> Q1 drain. Motor return must not flow through an Uno header.
Q1 / RPD | Logic-level N-MOSFET specified at 4.5/5 V gate drive, adequate current/thermal rating; 47-100 kOhm gate-to-source pull-down.
D1 | Flyback diode: cathode/band to motor +, anode to drain; rated for actual current and supply.

Do not power the motor from Uno 3.3V, 5V or GPIO. Keep MOTOR_ENABLED=false until the driver, regulated supply, fuse, disconnect, default-OFF behaviour and flow tests have passed. USB-powered Uno and the separate motor supply share GND only; do not join positive rails.

An independent power disconnect is required. Software timeout cannot stop a shorted MOSFET or guarantee recovery from a processor hang. Battery/charging design remains a separate configuration decision.

# 15 | Firmware installation and operation

The manual carries a frozen copy of the existing local bench v2 source in <b>docs/r14_uno_reference/PlantUno/</b>. It includes PlantUno.ino, PlantController.h and PlantView.h. No firmware behaviour was changed for this manual; source SHA-256 values are recorded in the adjacent evidence manifest.

<b>20.</b> Keep all three files in the PlantUno folder. Install Arduino IDE/CLI and the Arduino AVR Boards package. Select Arduino Uno / ATmega328P and the detected port, not Uno R4. Install <b>hd44780 by Bill Perry</b> using Library Manager; it is not bundled here.

<b>21.</b> With only the identified dry bench harness connected, compile and upload through the onboard USB socket. Disconnect the motor and all future supplies. Open serial at 115200 baud. Expect PlantUno bench v2 and LCD initialisation status=0.

<font face="Courier" size="8">arduino-cli compile --fqbn arduino:avr:uno<br/>  docs/r14_uno_reference/PlantUno</font><br/>CLI command shown wrapped; enter it as one line. Choose the actual port explicitly for upload.

Control / indication | Bench v2 behaviour
--- | ---
WATER | One simulated 0-5000 ms dose per press; knob sampled at start. Releasing WATER does not cancel. No automatic watering.
LAMP TEST | Cancels dose and illuminates reference LEDs. Release required before re-arm.
Triple LAMP | Three debounced presses within 1.2 s toggle VIEW; repeat to leave. WATER inhibited in VIEW.
VIEW display | Probe raw/relative moisture, pot raw/percent and WATER/LAMP states.
Normal display | Relative moisture, Ready MOTOR OFF, TEST dose, LAMP TEST or release instruction.
Moisture calibration | Dry=447, settled wet=221; clamped relative index. Not volumetric water content. Recalibrate for changed soil/probe.

Default: USE_STOP=false; MOTOR_ENABLED=false. Do not enable the motor simply by changing the constant. Historical v1 LCD fault evidence is superseded only for the saved v2 bench run, not for your newly assembled unit.

# 16 | Dry commissioning - record every result

Test | Method | Acceptance
--- | --- | ---
E01 | Power off; inspect every wire against schedule. | No crossed rails; all joints insulated; unknown modules isolated.
E02 | Uno + LCD first; power via onboard USB. | Stable supply; serial starts normally; LCD status=0 and steady readable text.
E03 | Remove power; add probe. Repower and observe VIEW. | Raw reading changes plausibly with probe condition. Record dry/wet values; protect electronics from water.
E04 | Remove power; add pot. Repower; sweep fully. | Raw approximately 0-1023, monotonic; clockwise increases. Record actual endpoints.
E05 | Add switches/LEDs with power off, then test. | Released WATER/LAMP=0; pressed=1. Lamp test lights all three reference indicators.
E06 | Set pot midrange, press WATER, keep held. | Single simulated dose; no repeat while held. Release/repress required.
E07 | Start simulated dose, then press LAMP. | Request cancels; release lockout clears after stable release.
E08 | Triple LAMP; attempt WATER; exit VIEW. | VIEW toggles; no dose in VIEW; release required on exit.
E09 | Measure D9 to GND during boot, WATER and LAMP. | LOW throughout normal bench tests; no motor connected.
E10 | Close after disconnecting; check routing and access. | No pinch/strain; all covers seat; planter removable; USB accessible.

Fault isolation

<b>LCD fault:</b> power off, verify GND/5V/A4/A5 and backpack labels. A contrast adjustment cannot repair an I2C bus fault. For resets/flashing backlight, inspect supply and watch for repeated startup messages.<br/><b>Input always pressed:</b> check COM/NO and latching variant.<br/><b>LED dark:</b> check polarity, resistor and correct pin.<br/><b>Pot/probe erratic:</b> check ground, wiper/output contact and connector identity.

HP4: save the serial log, measured rail values, wire check and photographs. Any failure stays open until corrected and retested. Prior bench evidence does not accept the installed harness.

# 17 | Wet acceptance, operation and care

Proceed only after the pump design hold is closed

<b>22.</b> Establish the actual pump rating, driver/supply/fuse selection, electrical isolation/strain relief, default-OFF tests and a controlled test procedure. Reassess switch functions and a clear stop/disconnect method before enabling delivery.

<b>23.</b> Leak-test the wet assembly with electronics removed or positively isolated. Use a catch tray and inspect all seams, riser routes and sensor entry. No fill volume is prescribed: determine and record a limit below unsealed entries, allowing for drain-back, splash and handling.

<b>24.</b> Check both drains and pump inlet remain clear with the chosen soil/guards. Verify that stopped flow does not siphon water into the planter or electronics. Correct the outlet arrangement if siphoning occurs.

<b>25.</b> Under supervision, calibrate volume versus run time at the installed lift and tube route using a measured vessel. Record repeatability and the selected maximum dose. Do not label the knob in millilitres from elapsed time alone.

<b>26.</b> Record wet-test results and reviewer disposition. Until complete, operate only in motor-disabled dry bench mode. No unattended-operation claim is made.

Routine use after acceptance

Check water level, intake, tube security and dry electronics before each supervised use. There is no reservoir-level interlock; prevent dry running by inspection and the pump's rated limits. Moisture indication is advisory. Repeated WATER presses can overwater.

Cleaning and service

Disconnect all power before lifting the planter or touching wiring/pump. Empty before moving; support the entire base. Clear both drains and intake screens. Clean only with materials and temperatures compatible with the actual print/coating. Never immerse the electronics tower.

Leakage, unexpected pump running, hot wiring or repeated resets: disconnect power, contain/empty water, record the defect and investigate. A software stop is not electrical isolation.

# 18 | Build and acceptance record

Complete for each physical assembly. Attach photographs, serial logs, measurements and any non-conformance record. A blank entry is not a pass.

Record | Value / evidence reference
--- | ---
Build ID / date / engineer | ________________________________________________
Git commit / manual issue | ________________________________________________
Printer / material / slicer / job | ________________________________________________
Board / LCD / probe variants | ________________________________________________
Switch size / action / lamp rating | ________________________________________________
Fasteners / thread process | ________________________________________________
Coupon / screw-fit evidence | ________________________________________________
PCB engagement / bottoming margin | ________________________________________________
USB / component minimum gaps | ________________________________________________
Harness / connector revision | ________________________________________________
Measured 5 V / 3.3 V rails | ________________________________________________
Dry tests E01-E10 / evidence | ________________________________________________
Firmware source hash / upload log | ________________________________________________
Pump / driver / supply / fuse | ________________________________________________
Leak / fill / siphon / flow evidence | ________________________________________________
Open defects / restrictions | ________________________________________________
Disposition / reviewer / date | ________________________________________________

<b>Current disposition at issue:</b> geometry digitally checked; actual fit and installed tests open. Pump, sounder, battery and illuminated-ring integration not electrically released. Panel USB-C excluded.

Any geometry or electrical change needs updated drawings, source identity and relevant repeated tests. Retain the original record; add a dated correction with the reason and affected part/wire/test IDs.

# 19 | Evidence, sources and revision control

Ref | Basis / limit
--- | ---
E1 | R14 verification.json and independent_mesh_check.json: digital CAD/STEP and mesh evidence; no physical qualification. Independent mesh check rerun 20 Sep 2026, PASS.
E2 | R13 retained geometry and kit drawings: tube/wire routes, fascia, planter and holder saddle. Carrier mounting instructions superseded by R14.
E3 | PlantUno bench v2 source and 15 Sep 2026 serial log: LCD status=0, lcd=OK, motor=OFF over saved five-second readback. Does not prove full commissioning.
E4 | User purchase screenshots supplied 20 Sep 2026: red/green/yellow ring-switch listings, mixed machine hardware and plastic screw listings. Selected variants not visible. Screenshots not reproduced or published.
S1 | Arduino Uno R3 official pinout and board documentation, checked 20 Sep 2026. Used to cross-check labels, 5 V logic and duplicate SDA/SCL.
S2 | Bill Perry / duinoWitchery hd44780 library documentation, checked 20 Sep 2026. Install separately; library licence GPL-3.0.

<link href="https://docs.arduino.cc/resources/pinouts/A000066-full-pinout.pdf" color="#167d8d">S1: Official Arduino Uno R3 full pinout</link><br/><link href="https://docs.arduino.cc/hardware/uno-rev3/" color="#167d8d">S1: Arduino Uno R3 board documentation</link><br/><link href="https://github.com/duinoWitchery/hd44780" color="#167d8d">S2: hd44780 library source and documentation</link>

<link href="https://github.com/skyhigh6/esp32-plant-station/blob/18ab0d889db349c712b43624d315e4f15ed3ebe2/mechanical/concept_rev14_uno/ACCEPTANCE.md" color="#167d8d">R14 acceptance register</link><br/><link href="https://github.com/skyhigh6/esp32-plant-station/blob/18ab0d889db349c712b43624d315e4f15ed3ebe2/docs/r14_uno_reference/evidence_manifest.json" color="#167d8d">Source snapshot and evidence hashes</link>

Issue history

<b>Issue A, 20 September 2026:</b> complete Uno assembly manual; R14/R13 configuration consolidated, wire colours/numbers assigned, purchased-part inspection added, bench v2 evidence reconciled. Original functional wiring diagrams created for this manual; diagrams are not photographs or exact component pin-layout drawings.

The manual is complete for the documented configuration. Open engineering decisions are explicit because no defensible voltage rating, purchased variant, pump current, physical fit or wet acceptance can be inferred from a listing image or a CAD pass.

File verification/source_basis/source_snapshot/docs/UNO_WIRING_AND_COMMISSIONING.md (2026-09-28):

# Arduino Uno plant station

**27 September 2026 interface revision:** The current switch, integrated LED and relay pin schedule is in [UNO_BUTTON_RELAY_REVISION_2026-09-27.md](UNO_BUTTON_RELAY_REVISION_2026-09-27.md). The wiring and motor-driver instructions below describe the earlier 15 September bench configuration and must not be used for the revised relay build. The R14 assembly manual and its frozen firmware snapshot remain historical issue records.

15 September 2026. Current electrical/firmware direction: classic 5 V Arduino Uno R3 / ATmega328P. Existing ESP32/SunFounder wiring is superseded for this build. Remove the SunFounder carrier from the circuit. Existing printed enclosure/PCB geometry is not Uno-compatible by assumption; bench mount first and measure before a mechanical redesign.

## Parts and wiring

Power off before rewiring. Assumed display: existing 16×2 QAPASS/PCF8574 I2C LCD. User reports a 3.3 V DC pump motor; rated/stall current unknown and no driver available. Motor and unidentified sounder remain disconnected.

| Uno label | Part |
|---|---|
| 5V | LCD VCC; dose potentiometer outer high terminal |
| GND | LCD GND; sensor GND; potentiometer outer low terminal; all switch returns and LED cathodes |
| A4 / SDA | LCD SDA — use analogue A4, not digital D4 |
| A5 / SCL | LCD SCL — use analogue A5, not digital D5 |
| 3.3V | Capacitive Soil Moisture Sensor v1.2 VCC, subject to module rating; no motor on this rail |
| A0 | Soil sensor AOUT |
| A1 | Potentiometer centre/wiper |
| D2 | WATER normally-open switch, other contact to GND |
| D3 | LAMP TEST normally-open switch, other contact to GND |
| D5 | 1 kΩ series resistor → red LED anode |
| D6 | 1 kΩ series resistor → blue LED anode |
| D7 | 1 kΩ series resistor → green LED anode |
| D4 | Optional STOP to GND; ignored unless USE_STOP is set true |
| D9 | Reserved motor-driver control, held LOW in supplied sketch |
| D8 | Reserved for a later identified sounder driver; leave disconnected |

Uno R3 has 5 V logic, so the 5 V PCF8574 LCD connects directly to A4/A5 without the ESP32 level shifter. Sensor is kept at 3.3 V; Uno ADC values will not necessarily span 0–1023. A4/A5 and dedicated SDA/SCL labels are the same bus. Each LED has its own resistor. Buttons use internal pull-ups. Never transfer ESP32 GPIO numbers to Uno terminals.

## Motor circuit still required

Use a regulated 3.3 V motor supply sized for measured startup/stall current. Motor + to supply +; motor − to logic-level N-MOSFET drain; source to supply GND; Uno GND to same GND. D9 through 100–220 Ω to gate, 47–100 kΩ gate-to-source pull-down. Flyback diode across motor with cathode/band to motor + and anode to drain. Driver must accept Uno's 5 V logic and be rated for the motor current. Do not power this 3.3 V motor from Uno 5V, a GPIO or the Uno 3.3V regulator. No driver or motor supply is selected until current is known.

## Sketch and setup

### v2 calibration and diagnostic view

User bench measurements: dry 447; watering transient 189; settled wet 221. The display uses dry=447 (0%) and settled wet=221 (100%); transient 189 is excluded as an endpoint. Moisture index is `(447 - raw) * 100 / 226`, clamped to 0–100%. This is a relative soil/probe index, not volumetric water content. Constants are saved in `PlantView.h` and survive resets as part of the sketch.

Press LAMP TEST three times within 1.2 seconds to toggle VIEW; each press and release must settle for 35 ms. Repeat to exit. Normal lamp-test behaviour is retained. VIEW updates every 100 ms: row 1 shows soil raw and moisture percentage; row 2 shows pot raw (0–1023), pot percentage and W/L input states (1=pressed). WATER cannot request a dose in VIEW; all buttons must be released before another dose is accepted on exit. View mode starts off after reset. Motor output remains disabled.

v2 compiled for Uno: 12418 bytes flash and 657 bytes static RAM. Host tests cover calibration/clamping, triple press, bounce, held input, timeout, clock rollover and dose inhibition/release after diagnostics.

Open `firmware/arduino/PlantUno/PlantUno.ino` in Arduino IDE. Keep its supplied `PlantController.h` in the same folder; this is a copy of the tested project controller. Select Arduino Uno (not Uno R4), and the freshly detected serial port. Install **hd44780 by Bill Perry** using Library Manager; it is already installed on this computer. This library is GPL-3.0; retain its licence if redistributing it.

LCD address and backpack mapping are auto-detected. LCD rows are overwritten without repeatedly clearing or switching the backlight. The LCD shows raw soil readings (not calibrated percent), readiness, release lockout, lamp test and simulated timed doses. USB serial is 115200 baud. LCD initialisation status 0 means success; nonzero is a fault. Runtime write errors disable display updates and report a fault; reset after repair. I2C transactions have a timeout.

The Uno ADC is scaled from 0–1023 to the existing controller's 0–4095 input. WATER samples the pot once for a 0–5000 ms simulated dose; releasing WATER does not cancel. LAMP TEST cancels and lights all three LEDs. Another dose requires stable release and a fresh press. Optional STOP is disabled by default. No moisture-triggered watering. MOTOR_ENABLED is false: D9 stays LOW regardless of requests. Do not enable merely by editing that constant: motor commissioning, display behaviour and fail-low pot wiring need review first.

## Acceptance sequence

1. Connect Uno and LCD only. Upload; confirm serial startup and LCD status=0. Display should show steady text. Turn the backpack contrast trimmer slowly if backlight is steady but characters are absent. If status is nonzero, repair power and I2C wiring first; contrast cannot repair bus communication.
2. If the whole backlight still flashes, disconnect power and check for loose supply/ground connections or shorts. Measure LCD VCC to GND and check serial for repeated startup messages. Flashing does not by itself prove a software fault.
3. Connect sensor and verify raw changes between dry/wet conditions. Record calibration in actual soil before adding a percentage. Keep electronics above the soil/water line.
4. Connect buttons and LEDs. With buttons released, serial water=0/lamp=0 and locked=0. Lamp test lights all three; release restores readiness after debounce. Check wiring if an input stays active.
5. Connect pot; check minimum/maximum dose, one request per press, no repeat while held, and lamp cancellation. Floating analogue inputs are not meaningful measurements. D9 must remain LOW throughout.
6. Motor testing remains pending driver, supply/current checks, diode, physical gate pull-down and calibrated flow. No wet commissioning or enclosure compatibility is claimed.

## Build verification

Uno target compilation passed: 11696 bytes flash, 605 bytes static RAM on Arduino AVR core 1.8.7. Existing controller host assertions passed. Uploaded successfully to newly detected CH340 COM9; serial startup confirms PlantUno bench v1. Over seven seconds, runtime timestamps advanced normally, released WATER/LAMP read 0, lockout read 0 and motor stayed OFF. LCD initialisation returned -4 and lcd=FAULT: LCD operation is not verified. Soil read 92–95 and scaled pot 368–380; these do not prove wiring or calibration. Evidence: `output/firmware_uno_2026-09-15/serial_readback.txt`. Next required physical check is LCD GND/5V/A4/A5 wiring, followed by reset.

References: https://docs.arduino.cc/hardware/uno-rev3/ and https://github.com/duinoWitchery/hd44780 .

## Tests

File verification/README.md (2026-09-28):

# Verification and source basis

| Location | Meaning |
|---|---|
| `cad/` | Original R17 digital records, independent mesh/section checks and actual-STL previews |
| `documents/` | PDF control/layout validation and clean rebuild results |
| `source_basis/` | Selected predecessor controls and frozen technical snapshots supporting revision bars |
| `REORGANISATION.json` | Scope, pre-cleanup baseline, publication transforms and exclusions |
| `release_checks.json` | Current print/input/firmware integrity and export check results |
| `firmware_host_tests.json` | Actual host assertion execution for this release |
| `plate_layout.json` | User-created 3MF source/publication hashes, metadata removal and comparison to all four current main models |
| `slicer_exports.json` | Four operator-supplied printer files; archive hashes, price/account metadata removal, executable-command preservation and G-code MD5 checks |
| `publication_review.json` | Outgoing publication-surface audit |

Snapshot path names identify their original configuration. Old links and rebuild commands in those records are historical; use the root README and PROJECT_CONTROL for current instructions. Some publication copies convert Windows-1252 text to UTF-8, remove private absolute paths and pin old GitHub links. The evidence register preserves original and publication hashes with the transformation record.

`source_basis/generators/` preserves the inherited R13/R15/R16 generation sources for traceability only. Their former checkout paths are no longer advertised as executable commands. Current R17 regeneration uses `technical/cad/build.py` and its frozen input. Inherited final STEP models remain editable under `technical/print/`.

Digital checks do not establish physical fit, strength, leakage, slicing suitability, calibrated volume or electrical acceptance. Original CAD runtime shutdown exit 1 remains an open anomaly. All physical actions A17-01–A17-13 remain open.

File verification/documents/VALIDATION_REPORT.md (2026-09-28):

# R17 / D02 validation record

Three PDFs / 40 pages. Identity, every effective-page row, section mappings, frame bounds and bar-to-matrix references passed. 28 frozen technical source hashes passed. All pages rendered and visually inspected; dense technical/diagram pages also inspected individually. Frame inset was corrected so all content remains inside the document frame.

A clean temporary rebuild using only delivered JSON, assets, change matrix and renderer reproduced all 40 rendered PNGs and all placement manifests exactly. Each document rebuild exited 0. PDF container bytes may vary with metadata; rendered content is the comparison basis.

46 selected STL/STEP files are copied byte-for-byte from their source revisions and now reside under technical/print, with their originating paths and hashes in its manifest. Only four main parts and one selected knob are for final assembly; trial coupons and alternative knobs are identified separately. No new physical, powered, wet or printer test was performed. Source-file validation does not establish physical fit, source rating or acceptance.

The reorganisation retained all three issued PDF files unchanged. Selected publication copies of predecessor text were converted to UTF-8, private absolute image paths removed and historical GitHub links pinned to the pre-cleanup commit. Original and publication hashes are both recorded in the evidence register. The 28 source-basis publication hashes and the clean 40-page rebuild have been verified again at the new paths.

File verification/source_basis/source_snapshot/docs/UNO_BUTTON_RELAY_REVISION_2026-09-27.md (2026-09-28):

# Uno button lamps and pump relay — 27 September 2026

For an operator-facing pin map and test sequence, open the [self-contained browser view](UNO_BUTTON_RELAY_BROWSER_VIEW_2026-09-27.html).

This is the current electrical interface for `firmware/arduino/PlantUno/PlantUno.ino`. It supersedes the switch-lamp and motor-driver pin instructions in the 15 September Uno bench note and the frozen R14 manual. The old documents remain evidence of their issued configurations.

## Confirmed choices and limits

- Three four-wire momentary buttons: WATER, LAMP TEST and STOP/cancel. Their two switch wires are electrically separate from their two LED wires. STOP is a software cancellation input, not an electrical isolation switch.
- Button colours and functions: green WATER/wet; yellow NEXT SCREEN/lamp test/dose in progress; red STOP/dry warning. The operator set **below 25% moisture** as too dry on 27 September.
- Rear lead colours, reported by the user for the buttons: **green = LED+**, **yellow = LED−**, **red and black = switch contacts**. Use red as the digital-input contact and black as the GND contact in this schedule; the switch pair is non-polarised. The lead assignment is a reported observation, not an electrical test result, so confirm each of the three physical buttons before power is applied.
- User reports that the proposed 5 V trigger relay module switches ON when its input is HIGH. The actual module, input current, coil supply requirements, power-on behaviour and contact rating have not been identified or measured.
- The user reports that the buttons, LCD, relay and pump work, with the pump supplied separately at 3.5 V. This is operator-reported function, not measured timing, current, volume or a rated-voltage check.
- `RELAY_ENABLED=true` remains active. D9 is set LOW at the start of `setup()` and goes HIGH only for an accepted WATER dose request, now 1,000–4,000 ms according to A1. D9 is high impedance during reset/bootloader time; its voltage and relay contact state have not been measured here.
- The pump supply was reported OFF before the LCD backlight revision was uploaded on COM8. Serial readback identified `PlantUno UI v6` and `relay=OFF` at rest. This boot initialised the LCD with status `0`; prior v5 and v4 runs had intermittent LCD communication faults, so the display connection still needs inspection. Physical confirmation of post-dose return remains open.

## Pin and wire schedule

| Uno terminal | Connection | Firmware behaviour |
| --- | --- | --- |
| D2 | Green WATER button's **red switch lead**; black switch lead to GND | `INPUT_PULLUP`; pressed reads LOW |
| D3 | Yellow LAMP TEST button's **red switch lead**; black switch lead to GND | `INPUT_PULLUP`; pressed reads LOW |
| D4 | Red STOP button's **red switch lead**; black switch lead to GND | `INPUT_PULLUP`; pressed reads LOW; cancels a dose |
| D5 | Series current limit to red STOP button's **green LED+ lead**; yellow LED− lead to GND | Slow blink below 25% moisture; fast double flash for rail-low A0; solid for STOP/lockout or lamp test |
| D6 | Series current limit to yellow LAMP TEST button's **green LED+ lead**; yellow LED− lead to GND | HIGH during a dose request or lamp test |
| D7 | Series current limit to green WATER button's **green LED+ lead**; yellow LED− lead to GND | Steady at 25% moisture or above, including during a dose; OFF for dry, sensor fault or STOP/lockout; ON for lamp test |
| D9 | Relay module logic input, physical wiring to verify | Enabled output; active HIGH for an accepted request; otherwise LOW |
| D10 | No connection to LCD VCC | Reserved; LCD backlight is controlled over I²C |
| A4 / A5 | Existing LCD SDA / SCL | I2C display; 5 V and GND per backpack marking |
| A0 / A1 | Existing soil-sensor output / dose-pot wiper | Sensor advisory; A1 sets 1,000–4,000 ms, sampled once when WATER starts |

Each button uses all four leads: red switch lead to its digital input, black switch lead to GND; green LED+ lead from its separate digital output through a suitable current limit, yellow LED− lead to GND. Identify the actual contacts and LED polarity for **each** button with power removed; the reported colour mapping is not a substitute for measurement. Confirm whether each purchased LED has an internal 5 V current limiter; choose and verify an external resistor if it does not. Do not connect an unverified LED directly to an Uno output. Keep the switch and LED circuits distinct even though both returns reach a ground rail.

WATER produces one timed request, yellow indication and D9 HIGH. The potentiometer's lowest ADC reading selects 1,000 ms and its highest selects 4,000 ms; an intermediate position is linear between those endpoints. The value is sampled once when WATER starts, so turning the knob cannot lengthen or shorten a running dose. The LCD shows a countdown and returns directly to the Status page's soil percentage when the request ends, even if WATER is still held. A sensor fault shows `CHECK SOIL A0` instead of a false percentage. STOP or yellow cancels on the next controller update; all switches then need a stable release before another WATER press.

Each debounced yellow press while idle cycles the LCD through Status (moisture and next duration), Raw (soil and knob ADC values), and Session (completed/cancelled counts and last completed duration). Holding yellow lights all three button LEDs. If yellow cancels a run, that press does not change page; after release the soil Status page returns. STOP shows an idle-press notice; holding it for two seconds clears the volatile session counters. These counters reset on power loss. A screen page does not initiate pumping. The soil reading is advisory only; an LCD fault does not inhibit a manual request. The prior upload initialised the LCD successfully, then lost write communication during a WATER request; the pages were not physically verified after that fault.

The red lamp blinks once per second while a valid A0 reading is **below 25%** on the installed 447-dry/221-wet calibration. At **25% or above**, the green lamp stays on. A state change needs 500 ms of stable readings so small ADC noise around 25% does not chatter. A raw A0 value of 20 or less is treated as an invalid rail-low sensor reading: green stays OFF, red gives a fast double flash, the Status page says `CHECK SOIL A0`, and serial prints `soil_state=FAULT`. STOP/lockout makes red solid; lamp test lights all three LEDs. Soil state never starts a pump dose automatically.

## LCD backlight timeout — UI v6

Keep LCD VCC connected to the Uno **5 V** supply and LCD GND to GND. Do **not** wire VCC to D10: the Uno R3 pinout specifies a 20 mA maximum per I/O pin, and this module's total LCD plus backlight current has not been measured. UI v6 uses the I²C backpack's backlight command, so LCD logic remains powered. The backlight goes off after 60 seconds without button use or a significant A1 knob movement (at least eight ADC counts). It wakes on any button press or knob movement. A pump request keeps it on, and completion or cancellation restarts the full 60-second interval at pump stop. Serial logs each successful backlight state change. If the LCD does not initialise, no backlight behaviour is claimed; inspect the intermittent LCD supply/I²C fault if status `-4` recurs. A full VCC power cut would need a rated switch and a design check for I²C back-powering before wiring it.

## Relay and pump circuit — rating and reset checks open

Use a **relay module with a logic input and onboard coil driver**, not a bare relay coil on D9. Confirm that a 5 V HIGH from the Uno meets the module's trigger specification without exceeding the D9 output-current limit. Power the module coil from a verified 5 V supply with enough current; connect its logic GND to Uno GND as its datasheet requires. Check the module's coil suppression and behaviour when its logic lead is open, during Uno reset and when either supply starts first. Provide an external D9-to-GND pull-down if needed for a measured default OFF state throughout boot. A sketch cannot control D9 during the bootloader interval.

The relay's **normally-open contacts** switch the pump's *separate, correctly rated* DC supply: supply positive → fuse/disconnect → COM → NO → pump positive; pump negative → supply negative. The contact circuit does not take pump power from D9, the Uno 5 V pin, or its 3.3 V pin. Size the supply, fuse, contacts, wiring and flyback suppression from the identified pump's operating and startup/stall current. For an ordinary brushed DC pump, verify a suitable diode or other suppression directly across the motor, polarity correct, and check its effect on contact release. Keep a physical power disconnect; a software STOP cannot interrupt welded contacts or a hung controller.

`RELAY_ENABLED` is `true` at the user's direction. `RELAY_TRIGGER` is set to `ActiveHigh` from the user's report. The operator reports a working pump path, but module identity, rated currents, supply voltage under load and contact state through reset have not been recorded. This is a supervised manual-dose system, with no automatic watering or proven volume calibration.

## Revised interface checks

1. With power removed, verify red/black as each switch pair by continuity: open released, closed pressed. Verify green as LED+ and yellow as LED− for each button using its part marking or a current-limited test. Identify each lamp's current-limiting arrangement separately. Record button part identifiers and ratings.
2. With the pump supply OFF, read back the revised sketch and confirm `relay=OFF` at rest. Press/release each button while watching serial. The v6 LCD initialised at status `0`, but earlier runs returned `-4` or lost write communication. Check supply stability, ground, A4/A5 and relay/pump suppression under load before treating screen pages as accepted. Sweep A1 from lowest to highest and verify that Status sets 1.0–4.0 seconds.
3. With a valid sensor reading, verify red blinks below 25% and green stays on at 25% or above; hold each side of the boundary for at least 500 ms. During a dose yellow lights and the moisture lamp retains its state. At pump stop, the screen should immediately return to the soil percentage, including if WATER remains held; release is still required for another dose. STOP cancels and makes red solid during lockout. Yellow lights all three while held and cycles the LCD pages. Hold STOP for two seconds to clear session counts. With A0 rail-low, check fast double red flash and `soil_state=FAULT`; do not interpret raw zero as wet.
4. With the pump supply OFF, verify the identified relay module's input current, HIGH=ON, LOW=OFF, and contacts OFF through power-up, reset and supply sequencing. Record any transient contact closure. For a supervised powered trial, measure the actual 1.0 and 4.0 second endpoints and delivered volume.
5. With LCD initialisation status `0`, leave the controls untouched for 60 seconds and observe `LCD backlight=OFF idle`. Press a button or move the knob by at least eight ADC counts and observe `LCD backlight=ON activity`. Finish or cancel a dose and verify the full 60-second interval starts again at pump stop. The LCD's 5 V wire stays on the 5 V terminal throughout.

The R14 assembly manual's bench results and source snapshot do not verify this revised wiring or the purchased hardware. Maintain a new build/test record rather than overwriting the historical one.

## Current UI v6 backlight upload record

On 27 September 2026, UI v6 compiled for `arduino:avr:uno` using 14,950 bytes of flash and 870 bytes of global RAM. After the operator confirmed the separate pump supply OFF, Arduino CLI uploaded it to the CH340 Uno on COM8. SHA-256 of `PlantUno.ino`: `0B702102A4EF74E1B1D6970B161125E77A69A9E28F2DA299324B71A1908D146F`.

Serial startup identified `PlantUno UI v6; relay HIGH; dose 1000..4000ms; LCD backlight idle 60s`. LCD initialisation returned `0`. With controls untouched, serial logged `LCD backlight=OFF idle` just after `t=60000`; a subsequent A1 movement (pot raw about 1016 to 964) logged `LCD backlight=ON activity`. Serial reported `relay=OFF` throughout. This verifies controller commands and I²C acknowledgement, not a direct visual observation of the backlight. Pump completion was not triggered in this check, so the post-dose timer reset remains to be observed. The previous intermittent LCD faults also remain open.

## Previous soil-return display upload record

On 27 September 2026, the UI v5 sketch compiled for `arduino:avr:uno` using 14,408 bytes of flash and 862 bytes of global RAM. After the operator confirmed the separate pump supply OFF, Arduino CLI uploaded it to the plant Uno on COM8. SHA-256 of `PlantUno.ino`: `E18A0A637255EE7214697E45D8E5005621363259B77CAAF760D99939AFBD0308`.

Serial startup identified `PlantUno UI v5; relay HIGH; dose 1000..4000ms; soil after dose`. At rest over approximately 1–10 seconds, raw soil was 454–455 (`0%`, `soil_state=DRY`), WATER/LAMP/STOP each read 0, `request=0` and `relay=OFF`. LCD initialisation returned `-4`; no dose was requested during this readback, so the immediate post-dose display has not been physically observed. The controller still requires a stable all-button release before another dose.

## Previous 25% lamp UI v4 upload record

On 27 September 2026, the 25% soil-indicator sketch compiled for `arduino:avr:uno` using 14,528 bytes of flash and 904 bytes of global RAM. After the operator confirmed the separate pump supply OFF, Arduino CLI uploaded it to the plant Uno, now enumerated as USB CH340 on COM8. SHA-256 of `PlantUno.ino`: `D5BEA386847DB1E126E490B675D9DDA22BF7BDBA945A2074FBD4533AC9108FEB`.

Serial identified `PlantUno UI v4; relay HIGH; dose 1000..4000ms; dry below 25pct`. At rest, raw soil was about 453 (`0%`, `soil_state=DRY`), all three buttons read 0, `request=0`, and `relay=OFF`. A physical WATER input was subsequently read as 1 with the pot near maximum; the sketch requested 3,975 ms and serial reported `relay=ON`, then `DOSE COMPLETE` and `relay=OFF`. The physical pump supply state at that later button press and actual relay contact/pump operation were not measured by this readback.

LCD initialisation returned `0`, followed by `LCD write failed` during the request and `lcd=FAULT` thereafter. Raw soil moved from about 453 dry to 208 (displayed 100%, `soil_state=WET`) and back to 443 (displayed 1%, `soil_state=DRY`) over the next roughly 25 seconds. This shows the software classification and 25% crossing, not a measured soil moisture change or a visual check of the button lamps. Correlate A0 readings with actual sensor position, wiring and supply before treating the index as plant moisture. No independent timing or volume measurement was made.

## Previous 1–4 second UI v3 upload record

On 27 September 2026, the revised sketch compiled for `arduino:avr:uno` using 13,986 bytes of flash and 861 bytes of global RAM. Arduino CLI uploaded it to the USB serial Uno on COM9 with the separate pump supply OFF. SHA-256 of `PlantUno.ino`: `72CD3DD4A3E21A96920D6ACA3EED329EB099DFBAC1F97C060491FF8E1E9BF676`.

Serial startup identified `PlantUno UI v3; relay HIGH; dose 1000..4000ms`. At rest for approximately 1–20 seconds, WATER/LAMP/STOP each read `0`, `request=0`, `relay=OFF`, and page `1`. The pot read approximately 120–123 of 1023 and soil read `0`. LCD initialisation returned `-4` and serial reported `lcd=FAULT`. The 1–4 second physical run time, new screen pages and button actions have not yet been checked on this upload. The browser demonstration is not connected to the Arduino.

## Previous one-second upload record

On 27 September 2026, the active-HIGH relay-trial sketch compiled for `arduino:avr:uno` using 12,546 bytes of flash and 658 bytes of global RAM. Arduino CLI uploaded it to the currently detected CH340 Uno on COM9; the upload exited successfully. SHA-256 of `PlantUno.ino`: `CB81B818E8B05F1232051A40C5416ECB9499EBC4F85AAEEF562B9A6C8EA6A40A`.

Post-upload serial startup identified `PlantUno relay trial; max 1000ms`. LCD initialisation returned `-4`. From approximately 1–11 s after reset, readback showed WATER/LAMP/STOP `0`, `request=0`, `relay=OFF`, pot raw approximately 85–86 and soil raw `0`. These are software readbacks, not measured pin voltage or proof of peripheral wiring. No button press, relay-contact measurement or powered pump run was performed by this upload.

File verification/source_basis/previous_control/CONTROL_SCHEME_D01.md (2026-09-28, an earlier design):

# Plant controlled restyling scheme — D01

Restyling date: 21 September 2026. Status: historical technical content, restyled; no engineering approval implied. Design revision Rn and document-restyling issue D01 are independent. Original document identities and dates remain recorded as source metadata. Newly assigned family IDs: PLANT-AM-001 (assembly/build manuals), PLANT-TR-001 (design review). R14 additionally retains PLANT-AM-R14-UNO as its original identity.

## Scope and lineage

Seven distinct PDFs are evidenced in the main checkout, local Git PDF history and release archives: AM R5, R6, R7, R8, R13, R14; TR R13. R5–R8 are explicitly successive illustrated assembly/build guides. R13 kit instructions continue the assembly purpose but reduce electrical scope; R14 expands it for Uno. This is a purpose-based family mapping, not evidence of a continuous historical document issue series. TR R13 is separate and must not be compared to an assembly guide as its predecessor.

R1–R4 project PDFs and their generation sources have not been located. No R9–R12 PDFs were found; existing mechanical README supplements explicitly continue R8 with changes. They supply technical-history evidence, not fictional PDF editions. TR R1–R12 and R14 PDFs have not been found. The earliest available AM R5 is an incomplete-history starting point, NOT relabelled R1. Unknown earlier introduction dates receive no guessed bar. Manufacturer reference PDFs are inventoried but not restyled or assigned Plant revisions.

## Shared visual template

A4 portrait; 40 mm left binding/history zone, 16 mm right margin; Helvetica body 9.5 pt/13 pt; numbered source sections; grey table headers and rules; black text and narrow black history lines. Illustrations retain aspect ratio and original technical meaning. Keep diagrams large enough to read. Title, revision control and LOEP precede the source content. Source technical status and cautionary language are preserved. No invented approvals, certification or completed tests.

LOEP lists every page at D01, because every page is newly restyled; it also maps source sections to current pages. D01 does not mean technical content was introduced at the latest design revision. Technical lineage is represented separately by the bars. Original page references must be updated to section references or the new page mapping; this is editorial only.

## Cumulative bars

R1 would be baseline with no bars, but no R1 output is created without its source. Use only the verified matrix entries. Attach a change ID and revision label to the affected surviving paragraph, table row or figure detail; do not mark an entire table or mixed illustration for one changed feature. Split mixed prose if necessary without changing its meaning. Narrow parallel labelled bars may occur beside content with multiple applicable historical changes. Preserve a prior label only for the surviving change; remove labels for superseded values/instructions. Changed figures with inseparable unchanged content are unmarkable at detail level: record in history instead of blanket-barring the figure. Pure movement, re-pagination, heading renumbering and D01 styling have no technical bar.

Verified means verified documentary comparison, not physical acceptance. An evidence row may be a technical design change, a new technical instruction/test criterion, an editorial explanation, formatting, deletion/supersession or unknown lineage. New evidence/status text can be technically material, but must never turn a CAD check into a physical pass.

## Production gates

Lead owns this scheme, the matrix and ambiguity resolution. Each GPT-5.6-sol worker owns exactly one document folder and receives original PDF, original generator/Markdown, predecessor evidence, the matrix and shared tooling. First produce AM R6/R7 sample, inspect all pages and cumulative bars, then release remaining production. Workers may propose matrix corrections but cannot silently introduce unsupported labels. All PDFs require source-content reconciliation, all-page rendering and visual review. Originals stay untouched; evidence copies are hashed. All work stays local.

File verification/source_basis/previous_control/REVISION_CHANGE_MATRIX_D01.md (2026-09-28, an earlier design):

# Verified sequential change matrix

Verified against local source PDFs/generators and mechanical README supplements on 21 September 2026. Dates below are documentary dates, not inferred approval dates. Exact source paths refer to the evidence folder unless stated otherwise. Bar eligibility is content-specific; this matrix does not authorise blanket section bars.

| ID | Transition / documentary date | Technical change and source | Surviving label / disposition |
|---|---|---|---|
| U01 | R1–R4 → R5 / Unknown | Earlier PDFs not found; R5 PDF and build_guide_r5.py are the earliest available guide. | No guessed R2–R5 bars. R5 incomplete-history starting point. |
| T06-1 | R5→R6 / 11 Sep 2026 | R6 pp1–4: sump 60 mm high, 56 mm internal depth, revised planter; R5 p5 uses earlier wet set. R6 explicitly requires replacing sump/planter/clip together. New reference pump envelope 38.5×25.5×43 mm, 3 mm allowance and resulting 13/10 mm clearances. | R6 on changed sump geometry/replacement and new pump-envelope checks. Retain on matching sump/pump geometry later, not obsolete separate-module instructions after R10. Overall 207×100×161, 4 mm floor, generic leak tests and dovetail/support-both instructions already exist in R5; no new R6 bar for those alone. |
| T06-2 | R5→R6 | R5 p5: 12 mm service notch, 7 mm clip bore. R6 pp3–4: 18 mm notch, 8.4 mm clip for 8 mm OD tube. | R6 through R8 on those dimensions/instructions. Not retained on R13/R14 integrated routes; clip removed R13. |
| T06-3 | R5→R6 | R6 pp2–3 adds 12.0/12.2/12.4 mm button coupon and explicit switch envelope/identification procedure. Existing three 12 mm fascia bores are not newly introduced at R6. | R6 on coupon selection/new envelope procedure where still present. Do not bar all button geometry. |
| T06-4 | R5→R6 | R5 p6 diagram labels a 5 V pump; R6 p6 explicitly states a 4.5 V nominal pump listing is not proof of 5 V compatibility. | R6 on this changed stated rating/evidence boundary, not an approval of either rating. It is absent from R7; do not invent a surviving numerical statement there. |
| T06-5 | R5→R6 | R5 p11 records seven meshes; R6 p8 records eight exported STLs including the coupon and associated new feature checks. | R6 on changed export count and added coupon/sump/pump checks, not blanket repeated mesh-quality assertions. Later revision-specific counts supersede it. |
| E06-1 | R5→R6 | R6 generated appearance image and reorganised assembly/worksheet; electrical logical boundary replaces detailed R5 compile-review diagrams. | Image/editorial reorganisation no technical bar; record omitted R5 compile/upload/reference diagrams as scope reduction, never copy back into later guides. Distinct new acceptance criteria may be recorded individually if evidenced. |
| T07-1 | R6→R7 / 12 Sep 2026 | R7 pp1–3: carrier centres 60×57 replace 60×55; 67×64 PCB drawing; ports upward; 72×46 top opening; old rear opening closed. | R7 on corrected carrier dimensions/orientation/access and associated coupon tests. R8 rotation supersedes installed orientation and top opening; original drawing's 60×57 remains R7 when explicitly cited. |
| T07-2 | R6→R7 | R7 pp2,5: LCD centres 75×31 replace 73×30; aperture 71.4×24.6 replaces 70×25; 3.0 bores replace 2.4; 6 OD pads; provisional M2.5/head ≤5.5. | R7 retained beside these surviving LCD dimensions and revised fitting criteria through R14. Not beside generic unchanged isolation statements. |
| T07-3 | R6→R7 | R7 pp2,6: dedicated carrier/LCD coupons, actual USB cable insertion acceptance. | R7 where the same coupon/check survives. Uno-specific coupon supersedes carrier coupon at R14. |
| D07-1 | R6→R7 | R6 old carrier/LCD patterns, small LCD fixing guidance and rearward USB access superseded (R7 p7). | Deletion/supersession history only. No obsolete instructions retained as current R7 instructions. |
| T07-4 | R6→R7 | R7 p5 and mechanical README: assumed carrier/module front stack 31.6 mm and remaining LCD gap 10.8 mm replace the earlier R5 1.6+20 mm carrier reference/20.8 mm gap. R6 preserves prior projections without new figures. | R7 on changed assumed envelope/gap only; LCD rear stack21.6 and seating plane y76 are retained, not new R7 geometry. All remain assumptions awaiting actual hardware. |
| T07-5 | R6→R7 | R7 p7 records ten exported STLs versus R6's eight, and corrected-interface/top-opening export checks. | R7 on changed count and check scope; mesh-quality properties and seven assembly solids are retained. Do not convert export checks into actual fit acceptance. |
| D07-2 | R6→R7 | R6 p7 ten-row worksheet becomes R7 p6 eight-row worksheet. New carrier/LCD/USB checks replace/reorganise explicit insert, pump-envelope, water-level, tube-route and dose-calibration rows. Related prose may survive elsewhere. | Record removed/consolidated standalone rows in §06 history; no deletion bars and no claim that removed acceptance requirements were completed. T07-3 covers new A1–A3 criteria. |
| T08-1 | R7→R8 / 12 Sep 2026 | R8 pp1–2: carrier rotated left; installed 57 horizontal×60 vertical; 28×20 left window; roof closed. | R8 on new installed coordinates/access/closed-roof requirements. R14 Uno mount supersedes carrier coordinates, but retained aperture and need to verify USB access remain. |
| T08-2 | R7→R8 | R8 pp1,7: supported upper fascia webs/sloped undersides and upper-boss coupon. | R8 where these specific features survive; later local roots and upper-gap change have separate labels. |
| T08-3 | R7→R8 | R8 p3: 10.4 ID piezo seat/4 mm outlet, 5.4 ID LED collars, qualified perimeter-gluing procedure. | R8 on these surviving dimensions/adhesive instructions in R13/R14. |
| T08-4 | R7→R8 | R8 p4: eight shaft-fit knob options, coupon, 11 mm engagement and ≥0.5 mm axial clearance. | R8 on surviving specific knob selection/installation instructions. |
| T08-5 | R7→R8 | R8 p5: explicit trial fastener allocations/lengths and boss retention tests. | R8 where actual allocation/lengths remain; R7 still applies to surviving LCD interface correction. Do not carry obsolete tray/clip screw allocation into R13. |
| T08-6 | R7→R8 | R8 p7 introduces proposed 0.4 mm nozzle/0.2 mm layers/four perimeters/five skin layers. | R8 only where those proposed settings survive; remains unvalidated. |
| U08-1 | R7→R8 | R8 BOM says 5 V pump; R6 explicitly says 4.5 V listing does not prove 5 V compatibility; R7 does not fix rating. | Record changed stated BOM basis; exact component/rating remains unverified. No engineering approval inferred. |
| T08-7 | R7→R8 | R8 p6 introduces an explicit 5 V pump BOM entry after R7's unspecified rating and R6's caveat. | R8 on the stated BOM rating with its actual-rating verification requirement; U08-1 remains the unresolved hardware identity. This bar records documentary change only. |
| T08-8 | R7→R8 | R8 p10: 22 exports, STEP re-import checks, 0.03 mm bounds/0.2 percent volume agreement, new knob/LED/piezo/boss feature checks. | R8 on changed counts/check scope/tolerances, preserving first-article pending and runtime caveats. Existing seven-solids/21-pair facts are not newly R8. |
| T09-1 | R8→R9 / 13 Sep 2026 correction heading | mechanical/concept_rev9/README.md: upper webs z153→158; cavity R2 vertical/R1 floor and specified edge/root treatments. Lower copied heading says 12 Sep: conflicting dates retained as source discrepancy. | R9 only on precisely matching surviving geometry; no missing R9 PDF invented. No label on general 'inspect roots' wording. |
| T10-1 | R9→R10 / date not established here | mechanical/concept_rev10/README.md: one-piece tower/sump, no dovetail assembly, body 207×100×158; revised planter and elevated trough. | R10 on surviving integrated body/no separate-module build. Trough superseded R11; no obsolete trough bars in R13. |
| T11-1 | R10→R11 / date not established here | mechanical/concept_rev11/README.md: short supported cable riser replaces long trough; integrated holder saddle, 6×2.5 tie slot, 4.8×1.5 provisional tie; no separate tray. | R11 on surviving integrated saddle/tie instructions. Cable-only riser superseded R12. |
| T12-1 | R11→R12 / date not established here | mechanical/concept_rev12/README.md: separate 10 mm tube x123/y92 and 8 mm pump wire x110/y92, crossover y92/z81, common intake; sensor entry initially y65/z128. | R12 on surviving separate routes. Sensor height superseded R13; no R12 label for z64 value. |
| T13-1 | R12→R13 / 14 Sep 2026 | R13 review p2 and mechanical README: hose clip/shelf/pilot removed; four main parts. | R13 on current 'no clip' and four-part requirements; deletion in history. |
| T13-2 | R12→R13 | R13 review p2: riser outside radius 1→7 mm and 3 mm top rounds; full lower fascia-support feet on the combined body, with concave 2 mm floor roots. The separate fascia part is retained. | R13 only adjacent to corresponding textual details. 'R1/R7/R3/R2' in this source paragraph are RADII, not design revisions. |
| T13-3 | R12→R13 | R13 review p2: old holder bores/pads removed; saddle/tie retained. | R13 on removed-hole/current no-screw instruction; R11 remains on retained tie geometry. |
| T13-4 | R12→R13 | R13 review p2 / kit sensor section: sensor centre z128→64, 8 mm hole lower edge at z60, local planter relief. | R13 on low sensor entry/relief and associated specific water-ingress limitation. Retain through R14. |
| T13-5 | R12→R13 | R13 review p3: 19 STL/STEP exports, four-solid assembly, six main pairs, 61 sampled lifts. | R13 on this revision-specific digital evidence; distinguish discrete sampling/runtime anomaly/unperformed tests. |
| U13-1 | R8→R13 document gap | R9–R12 README supplements explicitly retain R8 guidance with local changes; no PDF editions found. | Map only verified mechanical changes through the supplements. New R13 wording with unknown introduction gets no guessed R13 bar. TR R13 has no earlier same-family PDF; mechanical comparison is supporting evidence only. |
| T14-1 | R13→R14 / 20 Sep 2026 manual date | R14 pp1,3,6,20: Arduino Uno asymmetric mount/coupon replaces ESP32 carrier; retained R13 fascia/roof/planter and earlier side aperture. | R14 on Uno-specific mounting/coupon/fastener requirements; remove R7/R8 carrier-coordinate labels. |
| T14-2 | R13→R14 | R14 pp4,10–17: classic 5 V Uno, numbered wire schedules, motor-disabled bench v2, A4/A5 I2C; two active buttons, SW3 spare, D4/D8/D9 reserved. | R14 on new bench wiring, pin assignments, schedules, control behaviour and dry tests. Existing no-water/no-power cautions are not automatically new. |
| T14-3 | R13→R14 | R14 pp4,12,14,15: rings/sounder/cell isolated; panel USB-C excluded; 3.3 V pump reported, separate driver/supply remains a design hold. | R14 on new configuration dispositions and future E03 concept. No claim pump rating verified. |
| T14-4 | R13→R14 | R14 pp16,20: saved bench v2 LCD success/calibration/serial evidence; does not accept newly built harness. | R14 on new evidenced bench-status statement; all physical fit/wet acceptance remain open. |
| D14-1 | R13→R14 | Prior ESP32 carrier/pin concepts and dedicated STOP assumptions no longer describe Uno bench configuration. | Supersession history only; R14 technical content must not propagate backwards. |
| F01 | All outputs / 21 Sep 2026 | D01 title/control/LOEP, typography, binding margins, reflow, numbering, page-reference remapping. | Formatting/editorial; no technical bars. Original dates retained, no signatures added. |

## Unmarkable and uncertain items

Illustrations show multiple features; unless a changed detail can be isolated accurately, record the figure change in history and leave its margin unbarred. Restored source text absent from a clipped original PDF must be identified as a source-derived restoration, not silently claimed identical to the PDF. Retain a per-document content audit and bar-placement manifest with matrix IDs. A worker must escalate any materially new technical delta not covered above to the lead before labelling it.

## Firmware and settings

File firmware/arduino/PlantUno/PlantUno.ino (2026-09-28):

#include <Arduino.h>
#include <Wire.h>
#include <hd44780.h>
#include <hd44780ioClass/hd44780_I2Cexp.h>
#include "PlantController.h"
#include "PlantView.h"

#if !defined(ARDUINO_AVR_UNO)
#error "Select Arduino Uno (ATmega328P). This pin map is not for ESP32 or Uno R4."
#endif

constexpr uint8_t WATER_BUTTON = 2, LAMP_BUTTON = 3, STOP_BUTTON = 4;
// Red STOP, yellow LAMP TEST and green WATER lamps each need their own current limit.
constexpr uint8_t LOCKOUT_LED = 5, DOSING_LED = 6, READY_LED = 7;
constexpr uint8_t RELAY_MODULE_IN = 9;
enum class RelayTrigger { Unknown, ActiveHigh, ActiveLow };
constexpr RelayTrigger RELAY_TRIGGER = RelayTrigger::ActiveHigh; // User-reported module behaviour.
constexpr bool RELAY_ENABLED = true;
constexpr uint32_t MIN_PUMP_RUN_MS = 1000;
constexpr uint32_t MAX_PUMP_RUN_MS = 4000;
constexpr uint32_t LCD_BACKLIGHT_IDLE_MS = 60000;
constexpr uint16_t POT_ACTIVITY_DEADBAND = 8;
static_assert(MIN_PUMP_RUN_MS <= MAX_PUMP_RUN_MS, "Invalid pump duration range.");
static_assert(!RELAY_ENABLED || RELAY_TRIGGER != RelayTrigger::Unknown,
              "Set the measured relay trigger polarity before enabling D9.");
plant::PlantController controller(plant::ControllerConfig{35, MAX_PUMP_RUN_MS, MIN_PUMP_RUN_MS});
hd44780_I2Cexp lcd;
bool lcdReady = false;
bool backlightControlAvailable = false, backlightOn = false;
uint32_t lastActivityAt = 0;
uint16_t lastPotActivityRaw = 0;
bool relayApplied = false;
DebouncedPress pageButton;
SoilIndicator soilIndicator;
uint8_t page = 0;
enum class Notice : uint8_t { None, StopPressed, Cleared };
Notice notice = Notice::None;
uint32_t noticeAt = 0, doseStartedAt = 0, stopPressedAt = 0;
uint16_t completedCount = 0, cancelledCount = 0;
uint32_t lastCompletedMs = 0;
bool wasRunning = false, stopWasPressed = false, stopHoldHandled = false;
bool returnToSoil = false;
bool ignoreLampPageUntilRelease = false;
uint16_t potRaw = 0;
uint32_t lastDisplay = 0, lastSerial = 0;

plant::Inputs readInputs() {
  // Uno ADC is 10-bit; preserve the controller's full 0..4095 range.
  potRaw = analogRead(A1);
  const uint16_t pot = static_cast<uint16_t>(static_cast<uint32_t>(potRaw) * 4095UL / 1023UL);
  return {digitalRead(WATER_BUTTON) == LOW, digitalRead(LAMP_BUTTON) == LOW,
          digitalRead(STOP_BUTTON) == LOW, pot};
}

void apply(const plant::Outputs& out, SoilState soilState, uint32_t now) {
  if (RELAY_ENABLED) {
    const uint8_t active = RELAY_TRIGGER == RelayTrigger::ActiveHigh ? HIGH : LOW;
    relayApplied = out.pumpRequested;
    digitalWrite(RELAY_MODULE_IN, relayApplied ? active : (active == HIGH ? LOW : HIGH));
  }
  const bool red = out.lampTestActive || out.lockedOut || redSoilBlink(soilState, now);
  const bool green = out.lampTestActive || (!out.lockedOut && soilState == SoilState::Wet);
  digitalWrite(LOCKOUT_LED, red ? HIGH : LOW);
  digitalWrite(DOSING_LED, out.blueLed ? HIGH : LOW);
  digitalWrite(READY_LED, green ? HIGH : LOW);
}

bool writeRow(uint8_t row, const char* text) {
  if (lcd.setCursor(0, row) != 0) return false;
  bool ended = false;
  for (uint8_t i = 0; i < 16; ++i) {
    if (!ended && text[i] == '\0') ended = true;
    if (lcd.write(ended ? ' ' : text[i]) != 1) return false;
  }
  return true;
}

void show(int soil, SoilState soilState, uint8_t soilPercent, const plant::Outputs& out,
          const plant::Inputs& in, uint32_t now) {
  if (!lcdReady) return;
  char top[17] = "", bottom[17] = "";
  if (out.pumpRequested) {
    const uint32_t elapsed = now - doseStartedAt;
    const uint32_t left = elapsed < out.doseMs ? out.doseMs - elapsed : 0;
    snprintf(top, sizeof(top), "PUMP RUNNING");
    snprintf(bottom, sizeof(bottom), "Left %lu.%lus STOP",
             static_cast<unsigned long>(left / 1000), static_cast<unsigned long>((left % 1000) / 100));
  } else if (out.lampTestActive) {
    snprintf(top, sizeof(top), "LAMP TEST");
    snprintf(bottom, sizeof(bottom), "Screen %u of 3", static_cast<unsigned>(page + 1));
  } else if (!returnToSoil && notice != Notice::None && now - noticeAt < 2000) {
    switch (notice) {
      case Notice::StopPressed:
        snprintf(top, sizeof(top), "STOP pressed");
        snprintf(bottom, sizeof(bottom), "Hold 2s: clear");
        break;
      case Notice::Cleared:
        snprintf(top, sizeof(top), "COUNTERS CLEAR");
        snprintf(bottom, sizeof(bottom), "Pump is OFF");
        break;
      default: break;
    }
  } else if (out.lockedOut && !returnToSoil) {
    snprintf(top, sizeof(top), "PUMP LOCKED");
    snprintf(bottom, sizeof(bottom), "Release buttons");
  } else if (page == 0) {
    if (soilState == SoilState::Fault) {
      snprintf(top, sizeof(top), "CHECK SOIL A0");
      snprintf(bottom, sizeof(bottom), "Raw %4d", soil);
    } else {
      const uint32_t setMs = controller.plannedDoseMs(in.dosePotRaw);
      snprintf(top, sizeof(top), "%s %3u%% %s", soilState == SoilState::Dry ? "DRY" : "WET",
               static_cast<unsigned>(soilPercent),
               soilState == SoilState::Dry ? "WATER" : "READY");
      snprintf(bottom, sizeof(bottom), "Dose set %lu.%lu s", static_cast<unsigned long>(setMs / 1000),
               static_cast<unsigned long>((setMs % 1000) / 100));
    }
  } else if (page == 1) {
    snprintf(top, sizeof(top), "Soil raw %4d", soil);
    snprintf(bottom, sizeof(bottom), "Pot raw  %4u", static_cast<unsigned>(potRaw));
  } else {
    snprintf(top, sizeof(top), "OK%3u CUT%3u", static_cast<unsigned>(completedCount),
             static_cast<unsigned>(cancelledCount));
    if (completedCount) snprintf(bottom, sizeof(bottom), "Last %lu.%lu sec",
                                 static_cast<unsigned long>(lastCompletedMs / 1000),
                                 static_cast<unsigned long>((lastCompletedMs % 1000) / 100));
    else snprintf(bottom, sizeof(bottom), "No doses yet");
  }
  bool ok = writeRow(0, top);
  ok = writeRow(1, bottom) && ok;
  if (!ok || Wire.getWireTimeoutFlag()) {
    lcdReady = false;
    Serial.println(F("LCD write failed: check 5V/GND/SDA=A4/SCL=A5; reset after repair."));
  }
}

void updateBacklight(uint32_t now, bool active) {
  if (active) lastActivityAt = now;
  if (!lcdReady || !backlightControlAvailable) return;
  const bool shouldBeOn = now - lastActivityAt < LCD_BACKLIGHT_IDLE_MS;
  if (shouldBeOn == backlightOn) return;
  const int status = shouldBeOn ? lcd.backlight() : lcd.noBacklight();
  if (status != 0) {
    backlightControlAvailable = false;
    Serial.print(F("LCD backlight control failed, status=")); Serial.println(status);
    return;
  }
  backlightOn = shouldBeOn;
  Serial.println(shouldBeOn ? F("LCD backlight=ON activity") : F("LCD backlight=OFF idle"));
}

void setup() {
  // Establish the inactive level before switching D9 to output mode.
  if (RELAY_ENABLED) {
    digitalWrite(RELAY_MODULE_IN, RELAY_TRIGGER == RelayTrigger::ActiveHigh ? LOW : HIGH);
    pinMode(RELAY_MODULE_IN, OUTPUT);
  } else {
    digitalWrite(RELAY_MODULE_IN, LOW); // No pull-up while D9 is an input.
    pinMode(RELAY_MODULE_IN, INPUT);
  }
  pinMode(WATER_BUTTON, INPUT_PULLUP);
  pinMode(LAMP_BUTTON, INPUT_PULLUP);
  pinMode(STOP_BUTTON, INPUT_PULLUP);
  pinMode(LOCKOUT_LED, OUTPUT); pinMode(DOSING_LED, OUTPUT); pinMode(READY_LED, OUTPUT);
  Serial.begin(115200);
  Serial.println(F("PlantUno UI v6; relay HIGH; dose 1000..4000ms; LCD backlight idle 60s"));
  Wire.begin();
  Wire.setWireTimeout(25000, true);
  const int status = lcd.begin(16, 2);
  lcdReady = status == 0;
  Serial.print(F("LCD initialisation status=")); Serial.println(status);
  if (!lcdReady) Serial.println(F("LCD failed: check 5V/GND/SDA=A4/SCL=A5. Adjust contrast only after status=0."));
  if (lcdReady) {
    const int backlightStatus = lcd.backlight();
    backlightControlAvailable = backlightStatus == 0;
    backlightOn = backlightControlAvailable;
    if (!backlightControlAvailable) {
      Serial.print(F("LCD backlight control unavailable, status=")); Serial.println(backlightStatus);
    }
  }
  const plant::Inputs in = readInputs();
  pageButton.begin(millis(), in.lampTestButtonRaw);
  const uint32_t now = millis();
  lastActivityAt = now;
  lastPotActivityRaw = potRaw;
  soilIndicator.begin(now, analogRead(A0));
  apply(controller.begin(now, in), soilIndicator.state(), now);
}

void loop() {
  const uint32_t now = millis();
  const plant::Inputs in = readInputs();
  const bool potMoved = abs(static_cast<int>(potRaw) - static_cast<int>(lastPotActivityRaw)) >=
                        POT_ACTIVITY_DEADBAND;
  if (potMoved) lastPotActivityRaw = potRaw;
  if (wasRunning && in.lampTestButtonRaw) ignoreLampPageUntilRelease = true;
  if (!in.lampTestButtonRaw) ignoreLampPageUntilRelease = false;
  if (pageButton.update(now, in.lampTestButtonRaw) && !ignoreLampPageUntilRelease) {
    page = static_cast<uint8_t>((page + 1) % 3);
    returnToSoil = false;
    Serial.print(F("SCREEN ")); Serial.println(static_cast<unsigned>(page + 1));
  }
  if (in.stopButtonRaw && !stopWasPressed) {
    stopPressedAt = now;
    stopHoldHandled = false;
    returnToSoil = false;
    notice = Notice::StopPressed;
    noticeAt = now;
  } else if (!in.stopButtonRaw) {
    stopHoldHandled = false;
  }
  stopWasPressed = in.stopButtonRaw;
  const plant::Outputs out = controller.update(now, in);
  const int soil = analogRead(A0);
  const SoilState soilState = soilIndicator.update(now, soil);
  const uint8_t soilPercent = soilIndicator.percent();
  apply(out, soilState, now);
  const bool doseEnded = wasRunning && !out.pumpRequested;
  if (out.pumpRequested && !wasRunning) {
    doseStartedAt = now;
    returnToSoil = false;
    Serial.print(F("DOSE START ms=")); Serial.println(out.doseMs);
  } else if (doseEnded) {
    page = 0;
    returnToSoil = true;
    notice = Notice::None;
    if (controller.lockReason() == plant::LockReason::DoseComplete) {
      if (completedCount < 999) ++completedCount;
      lastCompletedMs = out.doseMs;
      Serial.println(F("DOSE COMPLETE"));
    } else {
      if (cancelledCount < 999) ++cancelledCount;
      Serial.println(F("DOSE CANCELLED"));
    }
  }
  wasRunning = out.pumpRequested;
  updateBacklight(now, in.waterButtonRaw || in.lampTestButtonRaw || in.stopButtonRaw ||
                       potMoved || out.pumpRequested || doseEnded);
  if (in.stopButtonRaw && !stopHoldHandled && now - stopPressedAt >= 2000) {
    completedCount = 0;
    cancelledCount = 0;
    lastCompletedMs = 0;
    stopHoldHandled = true;
    returnToSoil = false;
    notice = Notice::Cleared;
    noticeAt = now;
    Serial.println(F("SESSION COUNTERS CLEAR"));
  }
  if (now - lastDisplay >= 100) { lastDisplay = now; show(soil, soilState, soilPercent, out, in, now); }
  if (now - lastSerial >= 1000) {
    lastSerial = now;
    Serial.print(F("t=")); Serial.print(now);
    Serial.print(F(" soil=")); Serial.print(soil);
    Serial.print(F(" moisture_pct="));
    if (soilState == SoilState::Fault) Serial.print(F("INVALID"));
    else Serial.print(soilPercent);
    Serial.print(F(" soil_state="));
    Serial.print(soilState == SoilState::Fault ? F("FAULT") :
                 soilState == SoilState::Dry ? F("DRY") : F("WET"));
    Serial.print(F(" page=")); Serial.print(static_cast<unsigned>(page + 1));
    Serial.print(F(" pot_raw=")); Serial.print(potRaw);
    Serial.print(F(" pot=")); Serial.print(in.dosePotRaw);
    Serial.print(F(" water=")); Serial.print(in.waterButtonRaw);
    Serial.print(F(" lamp=")); Serial.print(in.lampTestButtonRaw);
    Serial.print(F(" stop=")); Serial.print(in.stopButtonRaw);
    Serial.print(F(" locked=")); Serial.print(out.lockedOut);
    Serial.print(F(" request=")); Serial.print(out.pumpRequested);
    Serial.print(F(" dose_ms=")); Serial.print(out.doseMs);
    Serial.print(F(" relay="));
    Serial.print(relayApplied ? F("ON") : F("OFF"));
    Serial.print(F(" lcd=")); Serial.println(lcdReady ? F("OK") : F("FAULT"));
  }
}

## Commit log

2026-09-09 Publish Plant Station R5 CAD, firmware scaffold and illustrated build guide
    [assembly.step, battery_tray.step, battery_tray.stl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]
2026-09-11 Add R6 pump sump and 12 mm button insert CAD package
    [assembly.step, battery_tray.step, battery_tray.stl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]
2026-09-11 Add R6 concept art and illustrated assembly documentation
2026-09-12 Correct R7 carrier and LCD mounts, USB access and assembly guide
    [assembly.step, battery_tray.step, battery_tray.stl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]
2026-09-12 Add R8 tower revision, knob options and manufacturing assembly pack
    [assembly.step, battery_tray.step, battery_tray.stl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]
2026-09-13 Add interactive R8 exploded STL explorer
2026-09-13 Close tower support gaps and soften R9 tower corners
    [assembly.step, battery_tray.step, battery_tray.stl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]
2026-09-13 Integrate R10 tower and sump with elevated internal cable route
    [assembly.step, battery_tray.step, battery_tray.stl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]
2026-09-13 Replace floating route with supported riser and integrate battery saddle
    [assembly.step, button_fit_coupon.step, button_fit_coupon.stl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]
2026-09-14 Enlarge R12 tube and pump routes and add above-planter sensor entry
    [assembly.step, button_fit_coupon.step, button_fit_coupon.stl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]
2026-09-14 Publish R13 enclosure and illustrated review package
    [assembly.step, button_fit_coupon.step, button_fit_coupon.stl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]
2026-09-15 Add R14 Arduino Uno tower mounts and complete mechanical release records
    [UNO-TH_Rev3e.brd, tower_sump_body_uno.step, tower_sump_body_uno.stl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]
2026-09-20 docs: refresh R14 Uno assembly and acceptance records
2026-09-20 docs: publish complete R14 Uno assembly and wiring manual
2026-09-28 Publish R17 controlled prototype and consolidate current repository
    Replace superseded revision trees and release archives with one current
    technical, firmware, docs, references, verification and releases structure.
    Preserve source-backed revision lineage and frozen input/export hashes.
    Include AM/TR/TS R17 D02 PDFs and editable sources, Uno UI v6 firmware,
    46 selected STL/STEP exports, independent checks and portable tooling.
    Verified: both Uno host assertion suites; clean 40-page document rebuild;
    current source/export hashes; six independent port sections; exact regenerated
    R17 STL hashes; complete staged publication audit and archive member hashes.
    CAD export generation completed but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
    [UNO-TH_Rev3e.brd, assembly.step, battery_tray.step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]
2026-09-28 Include controlled R17 plate layout and operator slicer exports
    Add the user-created four-plate Bambu Studio project and four supplied
    sliced printer exports to the current R17 structure and complete package.
    Preserve original incoming files in the verified external local archive.
    Remove account identifiers and filament-price fields from publication copies.
    Preserve all model geometry and executable printer commands; remove only
    the price comment from toolpaths and update their embedded MD5 checksums.
    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
    [fascia_r17.gcode.3mf, lid_r17.gcode.3mf, planter_r17.gcode.3mf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]
2026-10-11 Release combined R18 tower and fascia with D03 documents
    Open the pump-wire route for laying in terminated leads and close the three
    standalone LED apertures plus the speaker aperture. Retain the fitted Uno/relay
    mounts, illuminated-button wiring, lid, planter and Uno UI v6.
    Issue the complete R18 AM/TR/TS set, controlled sources, revision/evidence
    registers, inspection records, verified STL/STEP exports and release archive.
    Preserve R17 documents and original operator projects.
    Verified export hashes, independent mesh/port checks, six assembly pairs and
    45-page clean document rebuild. Physical acceptance remains open; recorded CAD
    runtime shutdown anomalies remain explicit.
